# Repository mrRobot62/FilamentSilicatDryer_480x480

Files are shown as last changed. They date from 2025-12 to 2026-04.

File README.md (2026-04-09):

# ESP32-S3 Filament & SilicaGel Dryer UI

> English documentation is available in [README_EN.md](README_EN.md).
> Diese README ist die deutsche Hauptfassung.

## Management Summary

> [!NOTE]
>
> Große Teile der Dokumentation basieren auf aktuellen Source-Code Ständen, Analysen und Reverse-Engineering. Die Dokumentation wurde primär von ChatGPT
> zusammengefasst und ausgearbeitet.
> 

**Technische Grundlage (Kurzüberblick):**
- **UI/Host:** ESP32‑S3, 480×480 Touchdisplay, **LVGL 9.4.x**
- **Client/Powerboard:** ESP32‑WROOM steuert Aktuatoren (Heater, Fans, Motor, Lamp) und liefert Telemetrie
- **Kommunikation:** UART/TTL (Serial2), ASCII‑Protokoll mit CRLF (Host ↔ Client)
- **Temperaturmessung:** externer **K‑Type Sensor** über **MAX31856** (zusätzliche Genauigkeit/Plausibilität)

Der **ESP32-S3 Filament & Silicat Dryer** ist ein spezialisiertes Steuer- und Bedienkonzept für einen kombinierten
Filament- und Silicagel-Trockner im Umfeld des FDM-3D-Drucks.

Beim FDM-3D-Druck stellt **Feuchtigkeit im Filament** eine der größten Qualitätsrisiken dar. Unterschiedliche Materialien
wie PLA, PETG, ABS, ASA oder technische Kunststoffe reagieren sehr unterschiedlich auf Feuchtigkeit und benötigen
jeweils **eigene Trocknungstemperaturen und Trocknungszeiten**.

Zusätzlich wird Filament häufig zusammen mit **Silicagel** gelagert, das Feuchtigkeit aufnimmt. Dieses Silicagel muss
regelmäßig regeneriert werden, was eine Trocknung bei hohen Temperaturen (typischerweise über 100 °C) über definierte
Zeitspannen erfordert.

Der hier beschriebene Filament-Silicat-Dryer verfolgt deshalb einen **All-in-One-Ansatz**:
- gleichzeitige Trocknung von bis zu zwei Filamentrollen
- Regeneration von Silicagel in einem rotierenden Korb
- Nutzung robuster, vorhandener Hardware eines Mini-Backofens
- vollständiger Ersatz der ursprünglichen Anzeige- und Steuerlogik

Die bestehende Hersteller-Hardware wurde **analysiert und reverse-engineered**. Das Powerboard inklusive Ansteuerung
von Heizung, Lüftern, Motor und Sensorik wurde unverändert weiterverwendet. Die ursprüngliche Benutzeroberfläche
(7-Segment-Anzeige, LEDs, einfache Tasterlogik) wurde vollständig entfernt und durch dieses Projekt ersetzt.

Das Ergebnis ist ein **sicheres, transparentes und erweiterbares System**, das sowohl für den täglichen Betrieb als auch
für Wartung, Service und Weiterentwicklung geeignet ist.

## Aktueller Release-Stand

- Version: `0.7.2`
- Fokus:
  - konfigurierbarer Parameterscreen auf dem HOST
  - NVM-persistente Fast-Shortcut- und Heater-Curve-Parameter
  - Display-Timeout mit einstellbarem Dimmfaktor und Wake-on-Touch-Schutz

## Sprache / Language

- Deutsche Hauptfassung: [README.md](README.md)
- Englische Fassung: [README_EN.md](README_EN.md)

> [!WARNING]
> 
> **USB darf nicht angeschlossen werden, während das Gerät am 230-V-Netz betrieben wird.** <br>
> Durch netzseitige Bezüge des PowerBoards können beim Anstecken von USB gefährliche Potentialunterschiede entstehen, die ESP32 oder PC beschädigen.<br>
> USB nur bei gezogenem Netzstecker, mit USB-Isolator oder über Trenntrafo verwenden.

# Grundgerät - EMPHSISM AFTO-1505D
Heißluftfritteuse 14L Airfryer Mini Backofen, Emphsism Heissluftfritteuse XXL Minibackofen 1800W

Link: https://www.amazon.de/Heißluftfritteuse-Emphsism-Heissluftfritteuse-Minibackofen-Zubehörteile/dp/B0D5QQ4SW4

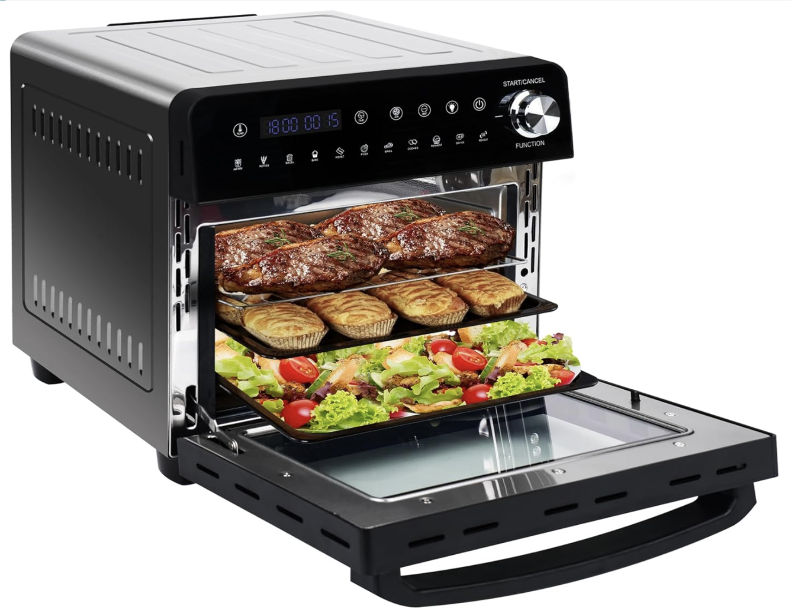
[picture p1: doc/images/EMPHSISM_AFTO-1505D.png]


## B-Ware kaufen !
> Die Geräte gibt es aber als B-Ware (ich habe mir ein solches Gerät gekauft). Kosten ca. 60€.
> Fehler in meinem Gerät (der Drehencoder funktionierte nicht - allerdings nur ein mechanischer Fehler :-) )

## Screenshots (Platzhalter)

### Main-Screen
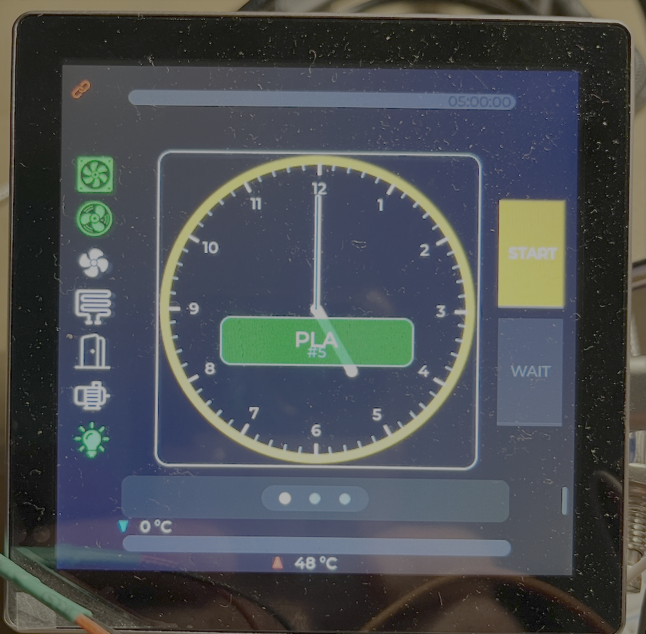
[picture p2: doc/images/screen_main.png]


### Filament-Config
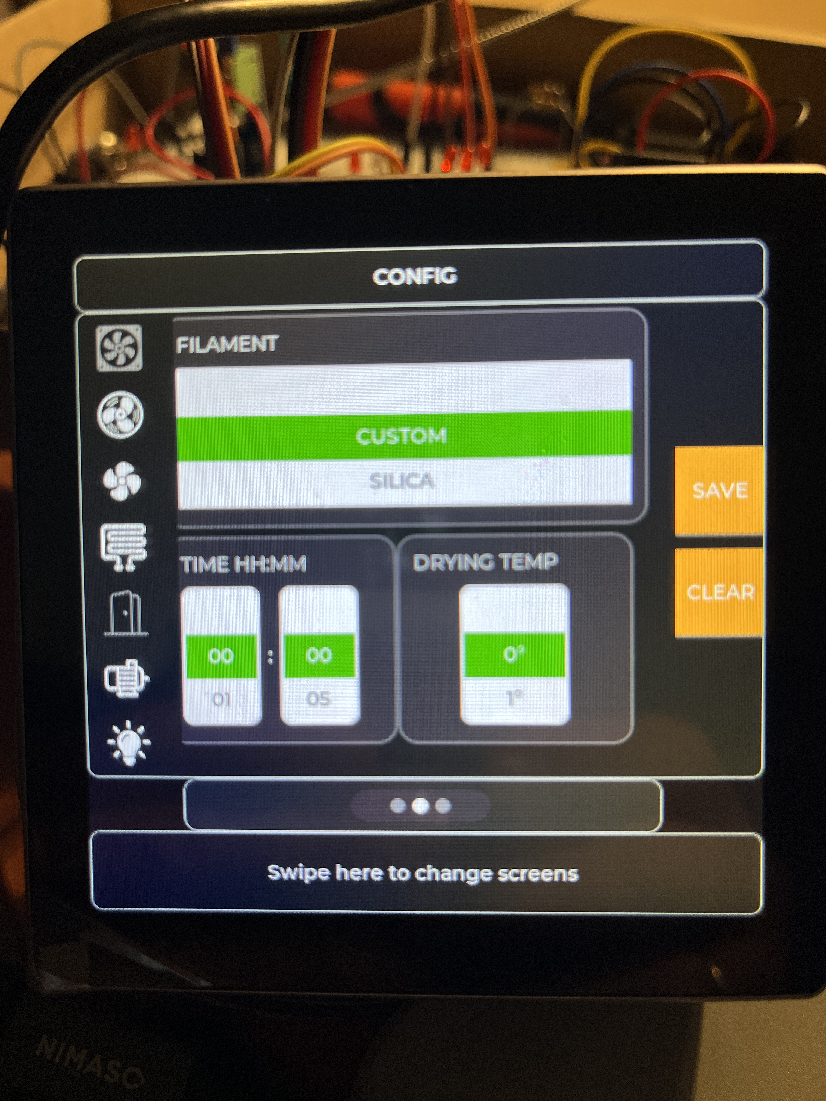
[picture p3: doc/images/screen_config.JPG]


### Hardware-Debug 
Diesen Screen nur mit **"Vorsicht"**  nutzen !

### Parameterscreen
- Der bisher ungenutzte LOG-Screen wurde durch `Parameter` ersetzt.
- Der Screen ist vertikal scrollbar und verwaltet hostseitige Grundparameter.
- Aktuell konfigurierbar:
  - Filament-Shortcuts fuer die vier Fast-Buttons aus `screen_main`
  - Heater-Curve-Parameter fuer die Presets `45C`, `60C`, `80C`, `100C`
  - `Display timeout` mit `Dimmfaktor (%)` und `Dimm-Timeout (min)`
- `SAVE` und `RESET` schreiben die Werte in das HOST-NVM und fuehren danach einen Reboot aus.
- Der erste Touch nach einem gedimmten Display hellt nur auf und loest absichtlich keine Funktion aus.

## Dokumentation

- Dokumentationsindex: [doc/README.md](doc/README.md)
- Softwarearchitektur: [doc/02_software_architecture/README.md](doc/02_software_architecture/README.md)
- User Guide: [doc/03_user_guide/README.md](doc/03_user_guide/README.md)

## Installation

> [!WARNING]
> 
> **!!!!! NIE USB verwenden, wenn Netzstecker eingesteckt ist !!!!!!!**

> [Installationsanweisung](doc/filament-silicagel-dryer_installation_v2.md)

## Systemarchitektur – Überblick

Zentrales Prinzip: **Oven Runtime State als Single Source of Truth**

### Komponenten-Diagramm
```mermaid
flowchart LR

  subgraph UX["UX Controller (ESP32 S3)"]
    S3["ESP32 S3 MCU"]
    TFT["480x480 Touch Display"]
    TOUCH["Touch Controller"]
    IO["GPIO Outputs"]
  end

  subgraph CLIENT["IO Controller (ESP32 WROOM)"]
    WROOM["ESP32 WROOM MCU"]
    UART2["UART TTL Interface"]
    OUT["Output Mask"]
    IN["Status Inputs"]
  end

  subgraph PWR["Powerboard (Reverse Engineered)"]
    PB["Powerboard Logic"]
    REL["Relays and Power Drivers"]
    SNS["Door and Safety Signals"]
  end

  subgraph SENS["External Temperature Sensor"]
    TC["K Type Thermocouple"]
    AMP["MAX31856 Interface"]
  end

  %% Connections
  S3 -->|"SPI or RGB"| TFT
  S3 -->|"I2C or SPI"| TOUCH

  S3 <-->|"UART TTL"| UART2
  UART2 <-->|"Serial Link"| WROOM

  WROOM -->|"Control Lines"| OUT
  OUT --> PB
  PB --> REL

  PB -->|"Status Bits"| IN
  IN --> WROOM

  TC -->|"Thermocouple"| AMP
  AMP -->|"SPI"| S3

  %% Notes
  NOTE1["UI never drives power directly"]
  NOTE2["Powerboard is authoritative source"]

  NOTE1 -.-> S3
  NOTE2 -.-> PB
```

## Entwicklungsphasen

> **Hinweis:**<br>
> **T1** (Display-/Touch‑Bring‑up) und <br>
> **T2** (erster LVGL‑Architektur‑Ansatz) waren bewusst frühe Grundlagenphasen. <br>
> Die wesentlichen, produktionsnahen Implementierungen starten ab <br>
> **T3** und sind entsprechend ab dort detailliert dokumentiert.

Siehe Dokumente unter `/docs`:
- [Entwicklungsphase T3 - Architektur / UX](doc/ESP32-S3_UI_T3_Zusammenfassung.md)
- [Entwicklungsphase T4 - screen_main](doc/ESP32-S3_UI_T4_Zusammenfassung.md)
- [Entwicklungsphase T5 - oven-logic](doc/ESP32-S3_UI_T5_Zusammenfassung.md)
- [Entwicklungsphase T6 - host/client Kommunikation (architektur/test)](doc/ESP32-S3_UI_T6_Zusammenfassung.md)
- [Entwicklungsphase T7 - host/client UX Integration](doc/ESP32-S3_UI_T7_Zusammenfassung.md)
- [Entwicklungsphase T8 - screen_dbg_hw](doc/ESP32-S3_UI_T8_Zusammenfassung.md)

## ⚠️ Sicherheitshinweis: USB-Verbindung im laufenden Betrieb

### Hintergrund
Das PowerBoard schaltet netzbetriebene Verbraucher (230 V AC) über TRIAC-basierte
Leistungsstufen. Obwohl der Niedervoltbereich (5 V / 3,3 V) funktional getrennt ist,
bestehen **elektrische Bezüge zum Netzbereich**, z. B. über TRIAC-Gate-Schaltungen,
Schutzdioden (PD-Netzwerke) und EMV-Strukturen.

Der ESP32 wird direkt vom PowerBoard versorgt und ist daher Teil dieser elektrischen
Domäne.

### Risiko beim Anschluss von USB
Beim Anschluss eines USB-Kabels wird die **USB-Masse des PCs/Laptops** direkt mit der
**Masse des ESP32** verbunden. Ist das Gerät gleichzeitig mit dem 230-V-Netz verbunden,
kann dies zu folgenden Problemen führen:

- ungewollten **Potentialunterschieden** zwischen PC und Gerät,
- **Beschädigung des ESP32**, des PowerBoards oder des USB-Ports am PC,
- im ungünstigen Fall zu gefährlichen Fehlerströmen durch EMV-Kopplungen oder Transienten.

Auch wenn keine direkte Gleichspannungsverbindung zu Phase (L) oder Neutralleiter (N)
messbar ist, können **kapazitive Kopplungen und kurzzeitige Überspannungen** auftreten.

### Verbindliche Regel
**USB darf nicht angeschlossen werden, während das Gerät am 230-V-Netz betrieben wird.**

### Erlaubte Nutzung
Eine USB-Verbindung ist nur unter einer der folgenden Bedingungen zulässig:
- Das Gerät ist vollständig **vom Netz getrennt** (Netzstecker gezogen), oder
- es wird ein **USB-Isolator** verwendet, oder
- das Gerät wird über eine **galvanisch getrennte Versorgung** betrieben
  (z. B. Trenntrafo).

### Empfehlung
- Firmware-Updates und Debugging **nur im spannungslosen Zustand** durchführen.
- Für Debugging im Betrieb ausschließlich **galvanisch isolierte Werkzeuge** verwenden.
- Der ESP32 ist als **interne Gerätelektronik** zu betrachten und nicht als
  USB-sichere Entwicklungsplattform.

Die Nichtbeachtung dieser Hinweise kann zu Hardware-Schäden führen.

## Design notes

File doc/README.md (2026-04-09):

# Documentation

This folder was restructured on top of the `v0.7.1` code line.

The active documentation is intentionally reduced to three maintained sections:

1. [Reverse Engineering and Hardware](01_reverse_engineering_and_hardware/README.md)
2. [Software Architecture](02_software_architecture/README.md)
3. [User Guide](03_user_guide/README.md)

Legacy material is still available in the archive:

- [Archive snapshot before the reorganization](archive/pre_reorg_v0.7.1/README.md)

## Scope of the active documentation

The new structure reflects the current product split:

- `HOST`: ESP32-S3 UI controller with LVGL, runtime state, parameter storage and communication control
- `CLIENT`: ESP32-WROOM hardware controller for outputs, telemetry and safety gating
- Reverse-engineered oven power board reused as actuator and supply stage

## Recommended next additions

The requested structure is complete for the current start. The next useful additions would be:

- a dedicated manufacturing and wiring guide
- a test and validation section
- a release and update workflow section

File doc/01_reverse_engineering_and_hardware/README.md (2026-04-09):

# Reverse Engineering and Hardware

This section documents the physical platform that the software is built around.

Contents:

1. [Power board analysis](01_powerboard_analysis.md)
2. [LVGL display and panel specifics](02_lvgl_display.md)
3. [KiCad hardware files](03_kicad.md)

## Current hardware split

- Base appliance: EMPHSISM AFTO-1505D mini oven / air fryer platform
- Reused original power board: heater, fans, lamp, motor, mains-side supply
- New `HOST` board: ESP32-S3 with 480x480 LVGL touch display
- New `CLIENT` board: ESP32-WROOM interface to the reused power board

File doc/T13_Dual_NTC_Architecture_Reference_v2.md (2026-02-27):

# T13 -- Dual‑NTC Architecture Reference (Erweitert)

Version: T13.0\
Status: Stabil, Referenzbasis für T14 SafetyGuard\
Zielgruppe: Entwickler, Techniker, Elektronik‑Interessierte

------------------------------------------------------------------------

# Übersicht

Die T13‑Architektur implementiert ein temperaturgeregeltes
Filament‑Trocknungssystem mit zwei physikalischen Temperatursensoren
(NTCs).\
Die Regelung erfolgt vollständig auf dem Host‑Controller (ESP32‑S3).

Die Architektur trennt bewusst:

-   Temperaturregelung (Control)
-   Sicherheit (Safety)
-   Hardwarezugriff (Client)
-   Darstellung (UI)

------------------------------------------------------------------------

# Sensor‑Architektur

## Chamber‑NTC (Control Sensor)

Eigenschaften:

-   10k NTC
-   10k Referenzwiderstand
-   angeschlossen an ADS1115 Channel 1
-   misst reale Lufttemperatur im Trocknungsraum

Verwendung:

-   einzige Grundlage der Temperaturregelung
-   einzige Grundlage für UI‑Anzeige
-   einzige Grundlage für Heater‑Steuerung

------------------------------------------------------------------------

## Hotspot‑NTC (Safety Sensor)

Eigenschaften:

-   100k NTC
-   100k Referenzwiderstand
-   angeschlossen an ADS1115 Channel 0
-   misst Nähe zur Heizquelle

Verwendung:

-   ausschließlich Sicherheitsüberwachung
-   keine Verwendung für Regelung

------------------------------------------------------------------------

# Systemarchitektur

``` mermaid
flowchart LR
    ChamberNTC --> ADS1115
    HotspotNTC --> ADS1115

    ADS1115 --> ClientESP32
    ClientESP32 -->|STATUS Frame| HostESP32

    HostESP32 --> OvenControl
    OvenControl --> HeaterControl

    OvenControl --> UI
```

------------------------------------------------------------------------

# Datenfluss im Betrieb

``` mermaid
sequenceDiagram
    participant ChamberNTC
    participant ADS1115
    participant Client
    participant Host
    participant OvenControl

    ChamberNTC->>ADS1115: Analogspannung
    ADS1115->>Client: ADC Raw Value
    Client->>Host: STATUS Frame
    Host->>OvenControl: Update runtimeState.tempChamberC
    OvenControl->>HeaterControl: ON / OFF
```

------------------------------------------------------------------------

# STATUS‑Protokoll (T13)

Frame Format:

    C;STATUS;<mask>;<adc0>;<adc1>;<adc2>;<adc3>;<tempHotspot_dC>;<tempChamber_dC>

Beispiel:

    C;STATUS;0020;26833;14065;0;0;-32768;227

Bedeutung:

-   adc1 = Chamber Sensor
-   tempChamber_dC = Chamber Temperatur in 0.1°C

------------------------------------------------------------------------

# Regelarchitektur (Control Layer)

Regelung basiert ausschließlich auf:

    tempChamberC

Nicht verwendet:

    tempHotspotC

------------------------------------------------------------------------

# Regel‑State‑Machine

``` mermaid
stateDiagram-v2
    [*] --> Idle
    Idle --> Heating : temp < target‑hysterese
    Heating --> Stabilizing : temp nahe target
    Stabilizing --> Heating : temp fällt
    Stabilizing --> Idle : target erreicht
```

------------------------------------------------------------------------

# Technische Implementierung

## Übersicht der Software‑Komponenten

``` mermaid
flowchart TD

    subgraph Client (ESP32‑WROOM)
        ADS[ADS1115 Driver]
        NTCConv[NTC Conversion]
        StatusGen[ProtocolStatus Generator]
    end

    subgraph Host (ESP32‑S3)
        HostComm[HostComm RX]
        ProtocolParse[Protocol Parser]
        RuntimeState[OvenRuntimeState]
        ControlLoop[Control Loop]
        Heater[Heater Output]
    end

    ADS --> NTCConv
    NTCConv --> StatusGen
    StatusGen --> HostComm

    HostComm --> ProtocolParse
    ProtocolParse --> RuntimeState
    RuntimeState --> ControlLoop
    ControlLoop --> Heater
```

------------------------------------------------------------------------

## Client‑Implementierung

Dateien:

-   FSD_Client.cpp
-   ClientComm.cpp

Aufgaben:

-   ADS1115 auslesen
-   ADC Werte in Temperatur konvertieren
-   STATUS Frame erzeugen
-   STATUS über UART senden

Beispielablauf:

``` cpp
adcRaw[1] = ads.readADC_SingleEnded(1);
tempChamber_dC = ntc_convert(adcRaw[1]);
sendStatusFrame();
```

------------------------------------------------------------------------

## Host‑Implementierung

Dateien:

-   oven.cpp
-   HostComm.cpp

Ablauf:

1.  STATUS Frame empfangen
2.  Werte in runtimeState übernehmen
3.  Regelalgorithmus ausführen
4.  Heater setzen

``` mermaid
flowchart TD
    STATUS[STATUS Frame] --> Parse
    Parse --> runtimeState
    runtimeState --> ControlLogic
    ControlLogic --> HeaterOutput
```

------------------------------------------------------------------------

## OvenRuntimeState

Zentrale Datenstruktur:

Beispiel:

    struct OvenRuntimeState
    {
        float tempChamberC;
        float tempHotspotC;
        float tempTargetC;

        bool heaterOn;
    };

Single Source of Truth für:

-   Regelung
-   UI
-   Logging

------------------------------------------------------------------------

## Regelalgorithmus (T13 Control Core)

Prinzip:

-   Thermostat‑basierte Regelung
-   Hysterese
-   overshoot prevention

Beispiel:

    if tempChamberC < target‑hysterese → heater ON
    if tempChamberC > target → heater OFF

------------------------------------------------------------------------

# Sicherheitsarchitektur

Safety erfolgt über:

-   Host‑Safety Logic
-   (zukünftig erweitert in T14 SafetyGuard Client)

------------------------------------------------------------------------

# Ergebnis der T13 Architektur

Eigenschaften:

-   stabile Regelung
-   keine Overshoot‑Instabilität
-   klare Trennung von Control und Safety
-   deterministic behaviour

------------------------------------------------------------------------

# Bedeutung für T14

T13 dient als stabile Grundlage für:

-   SafetyGuard Client Layer
-   Hardware Fail‑Safe Mechanismen

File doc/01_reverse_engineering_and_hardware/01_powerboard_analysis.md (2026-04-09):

# Power Board Analysis

## Goal

The original oven power board is reused instead of being redesigned from scratch. The reverse-engineering work exists to understand:

- power conversion and low-voltage supply
- actuator paths for heater, fans, lamp and motor
- door and sensor signals
- risks when connecting custom ESP32 hardware

## What is currently known

The reverse-engineering documents archived from the previous structure show a consistent pattern:

- the board contains the mains-side power stage and the low-voltage supply
- the heater is switched through a relay path
- 230 V loads such as lamp, motor and fan stages are driven through optocoupler / triac style paths
- the board exposes low-voltage control and status connections that are now driven by the `CLIENT`

## Functional block view

```mermaid
flowchart TD
    AC["230 V AC input"] --> PSU["Offline PSU section"]
    PSU --> LV["Low-voltage rail"]
    LV --> CLIENT["ESP32-WROOM client board"]

    CLIENT --> RELAY["Heater relay driver"]
    CLIENT --> TRIAC["Triac / optocoupler outputs"]
    CLIENT --> INPUTS["Door and sensor inputs"]

    RELAY --> HEATER["Heater"]
    TRIAC --> FAN12["12 V fan"]
    TRIAC --> FAN230["230 V fan"]
    TRIAC --> MOTOR["Silica basket motor"]
    TRIAC --> LAMP["Lamp"]

    INPUTS --> CLIENT
```

## Control lines used by the current firmware

The active output bit mapping is defined in `include/output_bitmask.h`:

- `BIT_FAN12V`
- `BIT_FAN230V`
- `BIT_LAMP`
- `BIT_SILICA_MOTOR`
- `BIT_FAN230V_SLOW`
- `BIT_DOOR`
- `BIT_HEATER`

The current `CLIENT` firmware treats the power board as hardware-authoritative:

- commands arrive from `HOST`
- output application happens on `CLIENT`
- telemetry and effective output truth are reported back to `HOST`
- safety gating remains on the `CLIENT`

## Important safety note

The board is mains-related. Existing project warnings remain valid:

- do not attach USB while the oven is connected to mains
- use isolation or disconnected mains supply during development
- treat the board as non-trivial mains hardware, not as a benign low-voltage module

## Source of historic details

Detailed pin traces, annotated photos and earlier analysis notes remain in:

- `doc/archive/pre_reorg_v0.7.1/legacy_docs/reverse_engineering/`
- `doc/archive/pre_reorg_v0.7.1/legacy_docs/images/`

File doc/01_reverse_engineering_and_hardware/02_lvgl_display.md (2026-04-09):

# LVGL Display and Panel Specifics

## Hardware identity

The current `HOST` uses an ESP32-S3 with a 480x480 touch display stack.

The code base references:

- panel: `HSD040BPN1-A00`
- controller family: `ST7701`
- backlight GPIO: `38`
- LVGL version: `9.4.0`

Relevant implementation files:

- `src/app/display/panel_hsd040bpn1.h`
- `src/app/display/display_hsd040bpn1.h`
- `src/app/display/display_hsd040bpn1.cpp`

## Integration characteristics

The display integration is not generic boilerplate. It has panel-specific constraints:

- RGB panel interface on the ESP32-S3
- separate register initialization sequence for the ST7701 family
- explicit backlight control
- touch integration handled separately from the display bring-up

## Known quirks from the current implementation history

- stable operation was achieved with a lower pixel clock than initially tested
- color order and pixel format needed panel-specific tuning
- the initialization sequence is tightly coupled to this exact panel family

## Display stack overview

```mermaid
flowchart LR
    APP["UI screens"] --> LVGL["LVGL 9.4"]
    LVGL --> GFX["Arduino_GFX display wrapper"]
    GFX --> RGB["ESP32-S3 RGB panel driver"]
    RGB --> ST7701["ST7701 init sequence"]
    ST7701 --> PANEL["HSD040BPN1 480x480 panel"]
    APP --> TOUCH["Touch controller"]
```

## Why this matters for documentation

This display section should remain separate because three concerns often get mixed up:

- panel electrical timing
- controller register initialization
- LVGL/UI behavior on top of a working framebuffer path

That separation will make future display bring-up changes less risky.

## Historic vendor files

Vendor packs, data sheets and flashing utilities are preserved in the archive:

- `doc/archive/pre_reorg_v0.7.1/legacy_docs/hardware/ESP32-S3 4848S04_Display/`

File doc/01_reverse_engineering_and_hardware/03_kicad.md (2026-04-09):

# KiCad

## Purpose

This section tracks the custom hardware files that belong to the adapted dryer controller setup.

## Available design assets

The repository already contains KiCad project files for the custom interface boards and variants.

Archived path:

- `doc/archive/pre_reorg_v0.7.1/legacy_docs/hardware/kicad/Filament-Silicagel-Dryer/`

Available project artifacts include:

- `.kicad_sch`
- `.kicad_pcb`
- `.kicad_pro`
- generated PDFs and gerbers
- alternative lochraster variants

## Recommended documentation baseline

The KiCad documentation should eventually describe:

1. which board is the currently valid build target
2. how the `HOST`, `CLIENT` and power board are wired together
3. which variants are legacy and which remain supported
4. where the series resistors, UART lines and sensor connections are placed

## Immediate interpretation of the current repository

Right now the KiCad data is valuable but not yet normalized. The archive keeps all variants, while the active documentation focuses on architecture first.

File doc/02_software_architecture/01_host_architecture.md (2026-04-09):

# HOST Architecture

## Responsibility

The `HOST` runs on the ESP32-S3 and owns:

- LVGL UI
- runtime state presented to the user
- drying logic and heater policy
- parameter persistence
- UART coordination with the `CLIENT`
- optional Wi-Fi / UDP diagnostics

The `HOST` does not directly drive the power board outputs.

## Main runtime modules

- `src/app/main.cpp`
- `src/app/oven/oven.cpp`
- `src/share/HostComm.cpp`
- `src/app/ui/**`
- `src/app/display/**`
- `src/app/host_parameters.cpp`

## Control flow

```mermaid
flowchart TD
    BOOT["setup()"] --> INIT["init UART, parameters, oven, UI"]
    INIT --> MAIN["main loop"]
    MAIN --> LVGL["LVGL tick and screen handling"]
    MAIN --> OVEN["oven runtime tick"]
    MAIN --> COMM["HostComm loop"]
    COMM --> STATUS["remote STATUS / ACK / PONG"]
    STATUS --> OVEN
    OVEN --> STATE["OvenRuntimeState"]
    STATE --> UI["screen rendering"]
    OVEN --> CMD["Host commands to client"]
```

## State model

The central host-side abstraction is `OvenRuntimeState` from `include/oven.h`.

It consolidates:

- target and measured temperatures
- effective actuator states from client telemetry
- communication health
- mode state such as `STOPPED`, `RUNNING`, `WAITING`, `POST`
- selected preset, heater profile and timing information

That state acts as the UI-facing single source of truth.

## Heater control model

The host decides heater intent, but not the final hardware truth.

The current logic in `oven.cpp` includes:

- preset-based target temperatures
- separate heater policies for low, mid, high and silica use cases
- min-on and min-off timing for relay protection
- hotspot and chamber safety limits
- comm-loss safe stop behavior

## Host architecture diagram

```mermaid
flowchart LR
    subgraph Host["ESP32-S3 HOST"]
        UI["LVGL screens"]
        OVEN["oven.cpp"]
        PARAM["host parameters"]
        COMM["HostComm"]
        DISP["display + touch"]
        NET["UDP diagnostics"]
    end

    UI --> OVEN
    PARAM --> OVEN
    OVEN --> UI
    OVEN --> COMM
    COMM --> OVEN
    DISP --> UI
    NET -. optional .-> OVEN
```

## Design consequence

The host is the policy and UX layer. It should remain free of assumptions that bypass client telemetry.

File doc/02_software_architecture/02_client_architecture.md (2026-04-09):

# CLIENT Architecture

## Responsibility

The `CLIENT` runs on the ESP32-WROOM and is the hardware-facing controller.

It owns:

- UART reception from the `HOST`
- output application to the power board
- telemetry generation
- safety gating close to the hardware
- sensor readout used for status reporting

## Main runtime modules

- `src/client/FSD_Client.cpp`
- `src/client/ClientComm.cpp`
- `src/client/heater_io.cpp`
- `src/client/sensor_ntc.cpp`
- `src/share/protocol.cpp`

## Architectural rules visible in the code

- incoming UART callbacks do not directly switch outputs
- mask changes are marked pending and applied from the main loop
- effective output truth is reported back, not just the requested mask
- host timeout forces a safe output mask
- door and thermal conditions can gate outputs locally

## Client processing diagram

```mermaid
flowchart TD
    RX["UART RX"] --> COMM["ClientComm"]
    COMM --> PARSE["parse host command"]
    PARSE --> PENDING["store pending mask / request"]
    PENDING --> LOOP["client loop"]
    LOOP --> APPLY["apply outputs safely"]
    LOOP --> SENS["read door / NTC / ADC"]
    APPLY --> STATUS["compose ProtocolStatus"]
    SENS --> STATUS
    STATUS --> TX["send STATUS / ACK / PONG"]
```

## Safety model

The client is deliberately hardware-authoritative:

- if the host disappears, the client forces a safe state
- if an output should not remain active due to safety conditions, the effective mask can differ from the requested mask
- the host UI must therefore trust client telemetry, not host intent alone

## Output mapping

The active output map is defined in `include/output_bitmask.h`:

- fan 12 V
- fan 230 V
- lamp
- silica motor
- fan 230 V slow
- door status bit
- heater

## Design consequence

The client should stay narrow and deterministic. Business logic belongs on the host; electrical truth belongs on the client.

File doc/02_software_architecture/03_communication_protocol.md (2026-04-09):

# Communication Protocol

## Role

The `HOST` and `CLIENT` communicate over `Serial2` with a line-based ASCII protocol.

Shared definitions live in:

- `include/protocol.h`
- `src/share/protocol.cpp`
- `src/share/HostComm.cpp`
- `src/client/ClientComm.cpp`

## Transport characteristics

- UART / TTL link
- messages are line-based
- frames are terminated with `CRLF`
- protocol is human-readable ASCII

## Message families

### Host to client

- `H;SET;XXXX`
- `H;UPD;SSSS;CCCC`
- `H;TOG;TTTT`
- `H;GET;STATUS`
- `H;PING`
- `H;RST`

### Client to host

- `C;ACK;SET;MMMM`
- `C;ACK;UPD;MMMM`
- `C;ACK;TOG;MMMM`
- `C;STATUS;...`
- `C;PONG`
- `C;RST`

## Status payload

`ProtocolStatus` currently contains:

- `outputsMask`
- `adcRaw[4]`
- `tempHotspot_dC`
- `tempChamber_dC`

The chamber temperature is the main control/UI temperature. The hotspot temperature is the safety temperature.

The current `C;STATUS` wire format is:

- `C;STATUS;<mask>;<a0>;<a1>;<a2>;<a3>;<hotspot_dC>;<chamber_dC>`

Some legacy comments in the code still describe the older single-temperature variant, but the codec implementation already uses the two-temperature format above.

## Protocol sequence

```mermaid
sequenceDiagram
    autonumber
    participant Host as HOST
    participant Client as CLIENT

    Host->>Client: PING
    Client-->>Host: PONG

    Host->>Client: SET or UPD or TOG
    Client-->>Host: ACK

    loop Periodic status polling
        Host->>Client: GET STATUS
        Client-->>Host: STATUS with mask ADC hotspot chamber
    end
```

## Robustness principles

The current implementation shows several explicit protocol design choices:

- both sides assemble complete lines before parsing
- stray bytes and partial garbage are tolerated up to a limit
- host and client both use timeout-based link supervision
- the host can safe-stop on comm loss
- the client can force safe outputs on host timeout

## Why the protocol matters architecturally

The protocol is not only transport. It is the contract that enforces the split between host policy and client hardware truth.

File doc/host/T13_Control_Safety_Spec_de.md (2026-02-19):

# T13 Steuerungs- und Sicherheits-Spezifikation

**Projekt:** FilamentSilicatDryer_480x480\
**Architektur-Version:** T13 (Dual-NTC, relaisfreundliche
Pulssteuerung)\
**Datum:** 2026-02-19

------------------------------------------------------------------------

# Änderungsprotokoll

## T13 (2026-02-19)

-   Einführung der Dual-NTC Architektur:
    -   `tempHotspot` (Sicherheitsüberwachung und thermische Dynamik)
    -   `tempChamber` (Primäre Regel- und UI-Temperatur)
-   Vollständige Entfernung des PT1/Bias-Thermalmodells.
-   Einführung preset-basierter Kammergrenzen (`chamberMaxC`).
-   Einführung eines relaisfreundlichen adaptiven Pulsreglers.
-   Einführung eines mehrstufigen Sicherheitssystems:
    -   Preset-basierte Kammergrenze
    -   Absolute Kammergrenze
    -   Hotspot Soft- und Hard-Grenzen
    -   Fail-Safe Sensorbehandlung

------------------------------------------------------------------------

# Systemübersicht

Das System besteht aus:

-   Host: ESP32-S3 (UI, Regelungslogik, Sicherheitslogik)
-   Client: ESP32-WROOM (Sensorerfassung, Aktorsteuerung)
-   Temperatursensoren: Zwei unabhängige NTC-Sensoren über ADS1115 ADC

Temperaturrollen:

  Sensor        Zweck
  ------------- ------------------------------------------------------
  tempChamber   Primäre Regeltemperatur
  tempHotspot   Sicherheitsüberwachung und dynamische Heizbegrenzung

Der Host ist die **Single Source of Truth** für alle Regel- und
Sicherheitsentscheidungen.

------------------------------------------------------------------------

# Sensorerfassung (Client)

ADC: ADS1115\
Gain: ±6.144 V\
Auflösung: 16-bit signed integer

Mapping:

  ADS Kanal   Zweck
  ----------- -------------
  CH0         tempHotspot
  CH1         tempChamber
  CH2         Reserviert
  CH3         Reserviert

RAW-Werte werden unverändert übertragen.

Temperaturübertragungseinheit:

-   deci-Grad Celsius (°C × 10)
-   Beispiel: 509 = 50.9°C

------------------------------------------------------------------------

# STATUS Protokollframe

Format:

    C;STATUS;<mask_hex>;<adc0>;<adc1>;<adc2>;<adc3>;<tempHotspot_dC>;<tempChamber_dC>

Beispiel:

    C;STATUS;0035;12345;11890;0;0;509;372

------------------------------------------------------------------------

# Preset-Modell

Jedes Preset definiert:

  Feld          Beschreibung
  ------------- -------------------------------------
  targetC       Zieltemperatur
  toleranceC    Hysterese
  chamberMaxC   Maximale zulässige Kammertemperatur

Beispiel (Silicagel Preset):

  Feld          Wert
  ------------- -------
  targetC       105.0
  toleranceC    2.0
  chamberMaxC   110.0

Regelband:

    lo = targetC − toleranceC
    hi = targetC + toleranceC

Beispiel:

    103°C … 107°C

------------------------------------------------------------------------

# Sicherheitsmodell

Sicherheitsebenen (höchste Priorität zuerst):

## Ebene 1 --- Absolute Kammergrenze

    CHAMBER_HARD_MAX_C = 120°C

Bei Überschreitung:

    Heater sofort AUS

## Ebene 2 --- Preset-Kammergrenze

    capC = min(chamberMaxC, CHAMBER_HARD_MAX_C)

Bei Überschreitung:

    Heater AUS

## Ebene 3 --- Hotspot Sicherheit

Relative Grenzwerte:

    HOTSPOT_SOFT_MAX_C = capC + 15°C
    HOTSPOT_HARD_MAX_C = capC + 30°C

Verhalten:

  Bedingung       Aktion
  --------------- ---------------------------
  ≥ Soft-Grenze   Verlängerung der OFF-Zeit
  ≥ Hard-Grenze   Heater AUS

Globale Begrenzung:

    HOTSPOT_HARD_MAX_C ≤ 200°C

------------------------------------------------------------------------

# Pulsregler (relaisfreundlich)

Relais benötigen langsame Schaltzyklen.

Standardparameter:

    HEAT_MS_MIN = 2000
    HEAT_MS_MAX = 8000

    REST_MS_MIN = 6000
    REST_MS_MAX = 60000

    MIN_TOGGLE_MS = 2000

Verhalten nahe Zieltemperatur:

    nearBandC = 3.0°C
    restNearTargetMinMs = 20000

Verhalten:

  Bedingung                    Ergebnis
  ---------------------------- ------------------------------------
  Weit unter Ziel              Moderate Heizpulse
  Nahe Ziel                    Minimale Heizzeit, lange OFF-Phase
  Schneller Hotspot-Anstieg    Verlängerte OFF-Phase
  Sicherheitsgrenze erreicht   Heater AUS

------------------------------------------------------------------------

# Fail-Safe Verhalten

Ungültiger Temperaturwert:

    temp = -32768

Verhalten:

    Heater AUS
    Optional Fault-Status

------------------------------------------------------------------------

# Regelautorität

Regelentscheidungen basieren ausschließlich auf:

    tempChamberC

Hotspot wird nur verwendet für:

-   Sicherheit
-   Timing-Anpassung

UI zeigt:

    tempChamberC

------------------------------------------------------------------------

# Beispiel: Silicagel Betrieb

Preset:

    target = 105°C
    tolerance = 2°C
    max = 110°C

Stabiler Betriebsbereich:

    100°C … 110°C

Overshoot wird verhindert durch:

-   chamberMaxC
-   Pulsregler
-   Hotspot-Sicherheitslogik

------------------------------------------------------------------------

# Implementierungsanforderungen

Host muss:

-   STATUS Frame parsen
-   Temperaturen verwalten
-   Pulsregler ausführen
-   Sicherheitslogik anwenden
-   Heater über Bitmaske steuern

Client muss:

-   ADS1115 lesen
-   NTC Temperaturen berechnen
-   STATUS Frames senden

------------------------------------------------------------------------

# Ende der Spezifikation

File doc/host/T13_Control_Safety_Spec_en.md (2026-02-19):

# T13 Control & Safety Specification

**Project:** FilamentSilicatDryer_480x480\
**Architecture Version:** T13 (Dual‑NTC, Relay‑friendly Pulse Control)\
**Date:** 2026‑02‑19

------------------------------------------------------------------------

# Change‑Log

## T13 (2026‑02‑19)

-   Introduced Dual‑NTC architecture:
    -   `tempHotspot` (Safety & thermal dynamics monitoring)
    -   `tempChamber` (Primary control & UI temperature)
-   Removed PT1/Bias thermal model completely.
-   Introduced preset‑based chamber limits (`chamberMaxC`).
-   Introduced relay‑friendly adaptive pulse scheduler.
-   Introduced multi‑layer safety model:
    -   Chamber preset cap
    -   Chamber hard cap
    -   Hotspot soft and hard caps
    -   Sensor fail‑safe handling

------------------------------------------------------------------------

# System Overview

The system consists of:

-   Host: ESP32‑S3 (UI, control logic, safety logic)
-   Client: ESP32‑WROOM (sensor acquisition, actuator control)
-   Temperature sensors: Two independent NTC sensors connected via
    ADS1115 ADC

Temperature roles:

  Sensor        Purpose
  ------------- -----------------------------------------------
  tempChamber   Primary control temperature
  tempHotspot   Safety monitoring and dynamic heating limiter

The Host is the **single source of truth** for all control and safety
decisions.

------------------------------------------------------------------------

# Sensor Acquisition (Client)

ADC: ADS1115\
Gain: ±6.144 V\
Resolution: 16‑bit signed integer

Mapping:

  ADS Channel   Purpose
  ------------- -------------
  CH0           tempHotspot
  CH1           tempChamber
  CH2           Reserved
  CH3           Reserved

RAW values transmitted unmodified.

Temperature transmission unit:

-   deci‑degrees Celsius (°C × 10)
-   Example: 509 = 50.9°C

------------------------------------------------------------------------

# STATUS Protocol Frame

Format:

    C;STATUS;<mask_hex>;<adc0>;<adc1>;<adc2>;<adc3>;<tempHotspot_dC>;<tempChamber_dC>

Example:

    C;STATUS;0035;12345;11890;0;0;509;372

------------------------------------------------------------------------

# Preset Model

Each preset defines:

  Field         Description
  ------------- -------------------------------------
  targetC       Control target temperature
  toleranceC    Hysteresis tolerance
  chamberMaxC   Maximum allowed chamber temperature

Example (Silicagel preset):

  Field         Value
  ------------- -------
  targetC       105.0
  toleranceC    2.0
  chamberMaxC   110.0

Control band:

    lo = targetC − toleranceC
    hi = targetC + toleranceC

Example:

    103°C … 107°C

------------------------------------------------------------------------

# Safety Model

Safety layers (highest priority first):

## Layer 1 --- Chamber Hard Limit

    CHAMBER_HARD_MAX_C = 120°C

If exceeded:

    Heater OFF immediately

## Layer 2 --- Preset Chamber Limit

    capC = min(chamberMaxC, CHAMBER_HARD_MAX_C)

If exceeded:

    Heater OFF

## Layer 3 --- Hotspot Safety

Relative thresholds:

    HOTSPOT_SOFT_MAX_C = capC + 15°C
    HOTSPOT_HARD_MAX_C = capC + 30°C

Behavior:

  Condition    Action
  ------------ ------------------------
  ≥ soft max   Increase REST duration
  ≥ hard max   Heater OFF

Global clamp:

    HOTSPOT_HARD_MAX_C ≤ 200°C

------------------------------------------------------------------------

# Pulse Scheduler (Relay‑Friendly Control)

Relay switching constraints require slow switching.

Default timing parameters:

    HEAT_MS_MIN = 2000
    HEAT_MS_MAX = 8000

    REST_MS_MIN = 6000
    REST_MS_MAX = 60000

    MIN_TOGGLE_MS = 2000

Near‑target behavior:

    nearBandC = 3.0°C
    restNearTargetMinMs = 20000

Behavior:

  Condition              Result
  ---------------------- -----------------------------
  Far from target        Moderate heat pulses
  Near target            Minimum heat, extended rest
  Fast hotspot rise      Extended rest
  Safety limit reached   Heater OFF

------------------------------------------------------------------------

# Fail‑Safe Handling

Invalid temperature sentinel:

    temp = -32768

If detected:

    Heater OFF
    Fault state optional

------------------------------------------------------------------------

# Control Authority

Control decisions use exclusively:

    tempChamberC

Hotspot temperature is used only for:

-   Safety enforcement
-   Adaptive timing adjustment

UI displays:

    tempChamberC

------------------------------------------------------------------------

# Example: Silicagel Operation

Preset:

    target = 105°C
    tolerance = 2°C
    max = 110°C

Result:

Stable operating range:

    100°C … 110°C

Overshoot prevented by:

-   chamberMaxC
-   pulse scheduler
-   hotspot adaptive limiting

------------------------------------------------------------------------

# Implementation Requirements

Host must:

-   Parse STATUS frame
-   Maintain chamber and hotspot temps
-   Apply pulse scheduler
-   Apply safety layers
-   Control heater via bitmask

Client must:

-   Read ADS1115
-   Convert NTC temperatures
-   Send STATUS frame periodically

------------------------------------------------------------------------

# End of Specification

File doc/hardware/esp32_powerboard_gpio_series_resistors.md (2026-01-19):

# ESP32-WROOM ↔ PowerBoard – GPIO-Serienwiderstände (220–330 Ω)

Dieses Dokument beschreibt **vollständig und detailliert**, welche GPIO-Pins des ESP32-WROOM
mit **Serienwiderständen (typisch 220–330 Ω)** an das PowerBoard angebunden werden sollen
und **warum** dies empfohlen ist.

Grundlage ist das von dir bereitgestellte GPIO-/Channel-Mapping.

---

## 1) Empfohlene Serienwiderstände (Hauptsignale: Aktoren & UART)

| Oven | GPIO | Channel | Widerstand | Info |
|---|---|---|---:|---|
| **OVEN_FAN12V** | **GPIO32** | **PIN_CH0** | **220–330 Ω** | Digitaler Ausgang zum PowerBoard-Treiberkanal (CH0). Serienwiderstand empfohlen (Schutz & EMV). |
| **OVEN_FAN230V** | **GPIO33** | **PIN_CH1** | **220–330 Ω** | Digitaler Ausgang (CH1) zum TRIAC-/Treiberpfad. Serienwiderstand empfohlen. |
| **OVEN_FAN230V_SLOW** | **GPIO25** | **PIN_CH2** | **220–330 Ω** | Digitaler Ausgang (CH2) zum TRIAC-/Treiberpfad. Serienwiderstand empfohlen. |
| **OVEN_LAMP** | **GPIO26** | **PIN_CH3** | **220–330 Ω** | Digitaler Ausgang (CH3) zum Treiberpfad. Serienwiderstand empfohlen. |
| **OVEN_SILICAT_MOTOR** | **GPIO27** | **PIN_CH4** | **220–330 Ω** | Digitaler Ausgang (CH4) zum TRIAC-/Motor-Treiberpfad. Serienwiderstand empfohlen. |
| **OVEN_HEATER** | **GPIO12** | **PIN_CH6** | **220–330 Ω** | Digitaler Ausgang (CH6) zum Relais-Treiberpfad (Heater). Serienwiderstand empfohlen. |
| **UART_TX (Client → PowerBoard)** | **GPIO17** | **TX2** | **220–330 Ω** | UART-TX vom ESP32 zum PowerBoard-RX. Sehr empfohlen für Signalintegrität & Schutz. |
| **UART_RX (PowerBoard → Client)** | **GPIO16** | **RX2** | **0–220 Ω (optional)** | UART-RX am ESP32. Standard 0 Ω; optional kleiner Serienwiderstand bei langen/noisy Leitungen. |

**Layout-Hinweis:**  
Serienwiderstände sollten **nah am ESP32-GPIO** platziert werden (Quellseite).

---

## 2) Signale, die *nicht* pauschal mit 220–330 Ω seriell ausgeführt werden

### 2.1 Door-Signal (Eingang)
| Oven | GPIO | Channel | Widerstand | Info |
|---|---|---|---:|---|
| **OVEN_DOOR_SENSOR** | **GPIO14** | **PIN_CH5** | **kein 220–330 Ω Standard** | Eingangssignal. Üblich sind Pull-up/Pull-down und ggf. RC-Filter. Serien-R eher 1–4,7 kΩ falls benötigt. |

**Typische Eingangsbeschaltung (Beispiele):**
- Pull-up: 10 kΩ nach 3,3 V (oder interner Pull-up)
- Optional RC-Filter: 1–4,7 kΩ + 10–100 nF
- Optional ESD-Schutz bei langen Leitungen

---

### 2.2 Analoge Eingänge (ADC)
| Oven | GPIO | Channel | Widerstand | Info |
|---|---|---|---:|---|
| *(ADC)* | GPIO36 | PIN_ADC0 | kein 220–330 Ω | Analogeingang. RC-Filter & Schutz gezielt auslegen. |
| *(ADC)* | GPIO39 | PIN_ADC1 | kein 220–330 Ω | Analogeingang. RC-Filter & Schutz gezielt auslegen. |
| *(ADC)* | GPIO34 | PIN_ADC2 | kein 220–330 Ω | Analogeingang. RC-Filter & Schutz gezielt auslegen. |
| *(ADC)* | GPIO35 | PIN_ADC3 | kein 220–330 Ω | Analogeingang. RC-Filter & Schutz gezielt auslegen. |

**Begründung:**  
Ein pauschaler Serienwiderstand kann die ADC-Messung verfälschen (Quellimpedanz, Sample-and-Hold).

---

### 2.3 SPI (MAX6675, optional)
| Oven | GPIO | Channel | Widerstand | Info |
|---|---|---|---:|---|
| *(MAX6675_SCK)* | GPIO18 | PIN_MAX6675_SCK | 220–330 Ω (optional) | SPI-Takt, schnelle Flanken → optional zur Dämpfung bei längeren Leitungen. |
| *(MAX6675_CS)* | GPIO5 | PIN_MAX6675_CS | 220–330 Ω (optional) | Optional bei längeren Leitungen. |
| *(MAX6675_SO / MISO)* | GPIO19 | PIN_MAX6675_SO | 0–220 Ω (optional) | Eingang am ESP32, meist 0 Ω ausreichend. |

---

## 3) Zusammenfassung – Was konkret bestücken?

### 3.1 Pflicht / Stark empfohlen
- **Alle Aktor-Steuerleitungen (MCU → PowerBoard)** mit **220–330 Ω**:  
  GPIO32, GPIO33, GPIO25, GPIO26, GPIO27, GPIO12
- **UART TX (GPIO17)** mit **220–330 Ω**

### 3.2 Optional / situationsabhängig
- **UART RX (GPIO16)**: 0 Ω Standard, optional 100–220 Ω
- **SPI SCK/CS**: optional 220–330 Ω bei längeren Leitungen

### 3.3 Nicht wie Ausgänge behandeln
- **Door Input (GPIO14)**: Pull-up + optional RC-Filter
- **ADC Inputs (GPIO36/39/34/35)**: gezielte Analogbeschaltung

---

## 4) Begründung – Warum Serienwiderstände?

### 4.1 Schutz der GPIOs
Serienwiderstände begrenzen den Strom bei:
- Kurzschluss gegen GND oder 3,3 V
- Fehlverdrahtung / Steckfehler
- Treiber-Kollisionen (MCU treibt gegen externen Treiber)

### 4.2 Bessere Signalqualität
GPIOs haben sehr schnelle Flanken. Leitungen wirken als Übertragungsleitungen:
- Überschwingen (Ringing)
- Fehltrigger an Treiber- oder Gate-Eingängen

Der Serienwiderstand dämpft diese Effekte zuverlässig.

### 4.3 EMV-Verbesserung
Gedämpfte Flanken → weniger hochfrequente Störenergie:
- geringere Abstrahlung
- weniger Einkopplung in Nachbarleitungen (z. B. UART)

### 4.4 Robustere Treiberansteuerung
Optokoppler, Transistorbasen und Gate-Netze verursachen Stromspitzen.
Der Serienwiderstand reduziert diese und erhöht die Robustheit.

### 4.5 Stabilere UART-Kommunikation
UART ist empfindlich auf Störungen rund um Start-/Stop-Bits.
Ein Serienwiderstand am **TX** ist eine einfache und sehr effektive Maßnahme.

---

## 5) Referenz: GPIO-Zuordnung (aus Projekt)

- OVEN_FAN12V = PIN_CH0 = GPIO32  
- OVEN_FAN230V = PIN_CH1 = GPIO33  
- OVEN_FAN230V_SLOW = PIN_CH2 = GPIO25  
- OVEN_LAMP = PIN_CH3 = GPIO26  
- OVEN_SILICAT_MOTOR = PIN_CH4 = GPIO27  
- OVEN_DOOR_SENSOR = PIN_CH5 = GPIO14  
- OVEN_HEATER = PIN_CH6 = GPIO12  

- UART: CLIENT_RX2 = GPIO16, CLIENT_TX2 = GPIO17

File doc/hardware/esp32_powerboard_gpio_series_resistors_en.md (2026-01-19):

# ESP32-WROOM ↔ PowerBoard – GPIO Series Resistors (220–330 Ω)

This document summarizes which ESP32-WROOM GPIO signals should be connected to the PowerBoard **with series resistors**
(typically **220–330 Ω**), and why this is recommended.

The mapping is based on the GPIO list you provided (ESP32-WROOM "Client" side).

---

## 1) Recommended Series Resistors (Main Control & UART)

| Oven | GPIO | Channel | Widerstand | Info |
|---|---|---|---:|---|
| **OVEN_FAN12V** | **GPIO32** | **PIN_CH0** | **220–330 Ω** | Digital output to PowerBoard driver channel (CH0). Series resistor recommended for protection and EMI reduction. |
| **OVEN_FAN230V** | **GPIO33** | **PIN_CH1** | **220–330 Ω** | Digital output (CH1) to TRIAC/driver path. Series resistor recommended. |
| **OVEN_FAN230V_SLOW** | **GPIO25** | **PIN_CH2** | **220–330 Ω** | Digital output (CH2) to TRIAC/driver path. Series resistor recommended. |
| **OVEN_LAMP** | **GPIO26** | **PIN_CH3** | **220–330 Ω** | Digital output (CH3) to driver path. Series resistor recommended. |
| **OVEN_SILICAT_MOTOR** | **GPIO27** | **PIN_CH4** | **220–330 Ω** | Digital output (CH4) to motor TRIAC/driver path. Series resistor recommended. |
| **OVEN_HEATER** | **GPIO12** | **PIN_CH6** | **220–330 Ω** | Digital output (CH6) to relay driver path (heater relay). Series resistor recommended. |
| **UART_TX (Client → PowerBoard)** | **GPIO17** | **TX2** | **220–330 Ω** | UART TX from ESP32 to PowerBoard RX. Strongly recommended to improve signal integrity and protect against wiring faults. |
| **UART_RX (PowerBoard → Client)** | **GPIO16** | **RX2** | **0–220 Ω (optional)** | UART RX at ESP32. Usually **0 Ω** is fine; **100–220 Ω** can help on long/noisy harnesses (optional). |

### Practical placement note
- Place the **series resistor close to the ESP32 GPIO pin** (driver side).  
  This improves protection and reduces ringing by damping the fast edge right at the source.

---

## 2) Signals that are *not* typically implemented with 220–330 Ω series resistors

These pins are present in your list, but they are usually treated differently.

### 2.1 Door input (OVEN_DOOR_SENSOR)
| Oven | GPIO | Channel | Widerstand | Info |
|---|---|---|---:|---|
| **OVEN_DOOR_SENSOR** | **GPIO14** | **PIN_CH5** | **no 220–330 Ω series (default)** | Door sensor is an **input**. Typical measures are **pull-up/pull-down**, optional **RC filtering**, and optionally a **small series resistor** (e.g. 1–4.7 kΩ) if you explicitly want ESD/current limiting on the input. |

**Typical input conditioning (examples):**
- Pull-up: 10 kΩ to 3.3 V (or internal pull-up if reliable)
- Optional RC filter: 1–4.7 kΩ series + 10–100 nF to GND (debounce/noise)
- ESD protection diode/clamp if the harness is long and exposed

> Note: A 220–330 Ω series resistor on an input is *not wrong*, but it is not the “standard default” measure like it is for **outputs** and **UART TX**. For noisy door lines, an RC filter is usually the more effective tool.

### 2.2 Analog inputs (ADC)
| Oven | GPIO | Channel | Widerstand | Info |
|---|---|---|---:|---|
| *(analog)* | GPIO36 | PIN_ADC0 | no 220–330 Ω series (default) | ADC input. Prefer RC filter and proper source impedance management. |
| *(analog)* | GPIO39 | PIN_ADC1 | no 220–330 Ω series (default) | ADC input. Prefer RC filter and proper source impedance management. |
| *(analog)* | GPIO34 | PIN_ADC2 | no 220–330 Ω series (default) | ADC input. Prefer RC filter and proper source impedance management. |
| *(analog)* | GPIO35 | PIN_ADC3 | no 220–330 Ω series (default) | ADC input. Prefer RC filter and proper source impedance management. |

**Why not “blindly” 220–330 Ω on ADC?**
- ADC readings can be affected by the source impedance and the sampling capacitor behavior.
- If you need protection/noise filtering, use a **defined RC filter** and confirm it against sampling requirements.

### 2.3 SPI (MAX6675) – optional depending on wiring length
You listed MAX6675 pins as an example (SCK=GPIO18, CS=GPIO5, SO/MISO=GPIO19).

| Oven | GPIO | Channel | Widerstand | Info |
|---|---|---|---:|---|
| *(MAX6675_SCK)* | GPIO18 | PIN_MAX6675_SCK | 220–330 Ω (optional) | SPI clock has fast edges; series resistor can reduce EMI/ringing on longer wires. |
| *(MAX6675_CS)* | GPIO5 | PIN_MAX6675_CS | 220–330 Ω (optional) | Optional for long harnesses; improves edge damping and protection. |
| *(MAX6675_SO / MISO)* | GPIO19 | PIN_MAX6675_SO | 0–220 Ω (optional) | Input to ESP32. Usually 0 Ω is fine; small resistor can help if ringing occurs. |

---

## 3) Summary (What to implement)

### 3.1 “Must / Strongly Recommended”
- **All PowerBoard control outputs**:  
  **GPIO32, GPIO33, GPIO25, GPIO26, GPIO27, GPIO12 → 220–330 Ω series**
- **UART TX to PowerBoard**:  
  **GPIO17 (TX2) → 220–330 Ω series**

### 3.2 “Optional / Situation-dependent”
- **UART RX from PowerBoard**:  
  **GPIO16 (RX2) → 0 Ω default, 100–220 Ω optional**
- **SPI SCK/CS** (if MAX6675 is wired via harness / longer distance):  
  **GPIO18, GPIO5 → 220–330 Ω optional**
- **SPI MISO**:  
  **GPIO19 → 0 Ω default, small series optional**

### 3.3 “Do not treat like outputs”
- **Door sensor input (GPIO14)**: prefer pull-up + optional RC filter
- **ADC inputs (GPIO36/39/34/35)**: prefer RC filter/protection designed for ADC behavior

---

## 4) Why series resistors are necessary / recommended

Series resistors (220–330 Ω) between MCU GPIOs and an external board/harness are a proven best practice for robustness.

### 4.1 GPIO protection (short circuits, wiring mistakes, contention)
In real builds, failures happen:
- A pin can be accidentally shorted to GND or 3.3 V,
- a connector can be misaligned,
- an external stage may momentarily drive a line when the MCU also drives it.

A series resistor limits the instantaneous current so the GPIO and/or the external stage is less likely to be damaged.

### 4.2 Signal integrity (damping fast edges, reducing ringing/overshoot)
GPIO outputs have fast edges; a cable/harness behaves like a transmission line:
- inductance and capacitance cause **ringing** and **overshoot**,
- this can lead to false switching (especially on sensitive driver inputs),
- it increases EMI emissions.

A 220–330 Ω resistor plus input capacitance creates a controlled edge and damps ringing.

### 4.3 EMI reduction (practical EMC improvement)
Lower edge rate = lower high-frequency energy:
- fewer radiated emissions,
- fewer conducted disturbances on the harness,
- less chance to upset adjacent lines (e.g., UART lines near actuator controls).

### 4.4 External driver input behavior (optos/transistors/triac gates)
PowerBoard inputs often go into:
- optocoupler LEDs,
- transistor bases,
- gate networks for MOSFETs / TRIAC gate drive.

These structures can draw current spikes during transitions. The series resistor reduces peaks and makes the system more tolerant.

### 4.5 UART stability (especially TX)
UART decoding is sensitive around thresholds on the start bit:
- ringing/overshoot can create extra edges,
- long harnesses and ground bounce make this worse.

A series resistor at **TX** is one of the simplest ways to increase UART robustness.

---

## 5) Implementation hints (practical)

- Put the resistor **close to the ESP32** (source side).
- Use one resistor **per line** (do not share).
- Prefer 220 Ω if you need slightly faster edges; prefer 330 Ω if wiring is long/noisy.
- If a line is particularly noisy, consider:
  - twisted pair with GND reference,
  - adding a defined RC filter (inputs),
  - improving grounding and return paths.

---

## 6) Reference: Provided GPIO mapping (for traceability)

- OVEN_FAN12V = PIN_CH0 = GPIO32  
- OVEN_FAN230V = PIN_CH1 = GPIO33  
- OVEN_FAN230V_SLOW = PIN_CH2 = GPIO25  
- OVEN_LAMP = PIN_CH3 = GPIO26  
- OVEN_SILICAT_MOTOR = PIN_CH4 = GPIO27  
- OVEN_DOOR_SENSOR = PIN_CH5 = GPIO14  
- OVEN_HEATER = PIN_CH6 = GPIO12  

- Serial2: CLIENT_RX2 = GPIO16, CLIENT_TX2 = GPIO17

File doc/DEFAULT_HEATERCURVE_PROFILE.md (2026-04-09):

# Default HeaterCurve Profile

Stand: aktueller Default-Code-Stand

Hinweis:

- Diese Tabelle zeigt die aktuellen Default-Werte aus dem Source-Code.
- `hysteresis`, `approachBand`, `holdBand` und `overshootCap` koennen zur Laufzeit ueber `host_parameters` ueberschrieben werden.
- Die Tabelle beschreibt also den Default-Fallback bzw. Initialzustand im Code.

| Parameter | `LOW_45C` | `MID_60C` | `HIGH_80C` | `SILICA_100C` |
|---|---:|---:|---:|---:|
| MaterialClass | `FILAMENT` | `FILAMENT` | `FILAMENT` | `SILICA` |
| Typische Presets | `PLA`, `TPU`, `PVA`, `BVOH` | `PETG`, `HIPS`, `PP` | `ABS`, `ASA`, `PA`, `PC`, `PPS` | `SILICA` |
| Preset-Temperaturbereich | `42.5..52.5°C` | `55.0..65.0°C` | `70.0..85.0°C` | `105.0°C` |
| Hysterese | `1.5°C` | `1.5°C` | `1.5°C` | `2.5°C` |
| Approach-Band | `10.0°C` | `10.0°C` | `10.0°C` | `10.0°C` |
| Hold-Band | `4.0°C` | `4.0°C` | `4.0°C` | `2.5°C` |
| Overshoot-Cap | `+2.0°C` | `+2.0°C` | `+2.0°C` | `+3.0°C` |
| Chamber-Max | `120.0°C` | `120.0°C` | `120.0°C` | `120.0°C` |
| Hotspot-Max | `140.0°C` | `140.0°C` | `140.0°C` | `140.0°C` |
| First Pulse Max | `10000 ms` | `11000 ms` | `12000 ms` | `45000 ms` |
| Bulk Pulse Max | `10000 ms` | `10000 ms` | `10000 ms` | `18000 ms` |
| Approach Pulse Max | `7000 ms` | `7000 ms` | `7000 ms` | `12000 ms` |
| Hold Pulse Max | `6000 ms` | `6000 ms` | `6000 ms` | `8000 ms` |
| First Soak | `45000 ms` | `45000 ms` | `45000 ms` | `60000 ms` |
| Reheat Soak | `30000 ms` | `30000 ms` | `30000 ms` | `35000 ms` |
| Safety Soak | `90000 ms` | `90000 ms` | `90000 ms` | `120000 ms` |
| Bulk Enable Below Target | `20.0°C` | `20.0°C` | `20.0°C` | `25.0°C` |
| Approach Enable Below Target | `10.0°C` | `10.0°C` | `10.0°C` | `12.0°C` |
| Reheat Enable Below Target | `3.0°C` | `3.0°C` | `2.0°C` | `4.0°C` |
| Force-Off Before Target | `1.0°C` | `1.0°C` | `1.0°C` | `1.0°C` |
| First-Pulse Force-Off Before Target | `2.0°C` | `2.0°C` | `2.0°C` | `2.0°C` |
| Hotspot Reheat Block | `+5.0°C` | `+5.0°C` | `+5.0°C` | `n/a` |
| Hotspot Force-Off | `+10.0°C` | `+10.0°C` | `+10.0°C` | `n/a` |
| Fan Min Switch | `5000 ms` | `5000 ms` | `5000 ms` | `n/a` |
| Fan Fast After Heat | `12000 ms` | `12000 ms` | `12000 ms` | `n/a` |
| Resume Soak | `12000 ms` | `12000 ms` | `12000 ms` | `n/a` |
| Resume Min Soak | `5000 ms` | `5000 ms` | `5000 ms` | `n/a` |
| Resume Hot-Target Soak | `7000 ms` | `7000 ms` | `7000 ms` | `n/a` |
| Resume Short Pulse | `6000 ms` | `6000 ms` | `6000 ms` | `n/a` |
| Resume Long Pulse | `8000 ms` | `8000 ms` | `8000 ms` | `n/a` |

## Kurzfazit

- `LOW_45C` und `MID_60C` unterscheiden sich aktuell nur leicht.
- `HIGH_80C` hat bereits frueheres Reheat als die beiden darunter.
- `SILICA_100C` ist klar als eigenes High-Temp-Profil aufgebaut.

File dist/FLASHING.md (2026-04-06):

# Flashing

Dieses Release enthaelt pro ESP zwei relevante Artefaktarten:

- `*_firmware.elf`: Debug-/Analyse-Artefakt aus dem Build
- `*_flash.bin`: zusammengefuehrte Flash-Datei fuer direktes Schreiben auf den ESP

Empfohlene Flash-Offets der Einzeldateien:

- Host ESP32-S3:
  - `0x0000` `bootloader.bin`
  - `0x8000` `partitions.bin`
  - `0xE000` `boot_app0.bin`
  - `0x10000` `firmware.bin`

- Client ESP32:
  - `0x1000` `bootloader.bin`
  - `0x8000` `partitions.bin`
  - `0xE000` `boot_app0.bin`
  - `0x10000` `firmware.bin`

Alternativ direkt die jeweilige `*_flash.bin` verwenden.

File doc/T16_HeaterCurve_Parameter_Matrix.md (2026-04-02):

# T16 HeaterCurve Parameter Matrix

Stand: aktueller Source-Stand nach `T16_Phase_4.1`

## Profil-Zuordnung

- `LOW_45C`: niedrige Filament-Trocknungstemperaturen, z. B. PLA/TPU/BVOH/PVA
- `MID_60C`: mittlere Filament-Trocknungstemperaturen, z. B. PETG/HIPS/PP
- `HIGH_80C`: hohe Filament-Trocknungstemperaturen, z. B. ABS/ASA/PA/PC/PPS
- `SILICA_100C`: Silicagel-Trocknung im Bereich um 100 C

## Parameter-Tabelle

| Parameter | Info | `LOW_45C` | `MID_60C` | `HIGH_80C` | `SILICA_100C` |
|---|---|---:|---:|---:|---:|
| `materialClass` | Grobe Materialgruppe fuer bestehende Speziallogik im Host. | `FILAMENT` | `FILAMENT` | `FILAMENT` | `SILICA` |
| `hysteresisC` | Hysterese im `HOLD`-Bereich der Basis-Policy. Bestimmt, wie weit die Chamber unter Target fallen darf, bevor wieder geheizt wird. | `1.5 C` | `1.5 C` | `1.5 C` | `2.5 C` |
| `approachBandC` | Abstand zum Target, ab dem von `BULK_HEAT` nach `APPROACH` gewechselt wird. | `10.0 C` | `10.0 C` | `10.0 C` | `10.0 C` |
| `holdBandC` | Abstand zum Target, ab dem in den `HOLD`-Bereich gewechselt wird. | `4.0 C` | `4.0 C` | `4.0 C` | `2.5 C` |
| `targetOvershootCapC` | Harte Host-Safety-Grenze relativ zum Target. Wird sie ueberschritten, setzt der Host `safetyCutoffActive`. | `+2.0 C` | `+2.0 C` | `+2.0 C` | `+3.0 C` |
| `chamberMaxC` | Absolute maximale Chamber-Temperatur fuer die Host-Safety. | `120.0 C` | `120.0 C` | `120.0 C` | `120.0 C` |
| `hotspotMaxC` | Absolute maximale Hotspot-Temperatur fuer die Host-Safety. | `140.0 C` | `140.0 C` | `140.0 C` | `140.0 C` |
| `firstPulseMaxMs` | Maximaldauer des allerersten Heizpulses nach Start. Begrenzt den initialen Energieeintrag. | `10000 ms` | `10000 ms` | `11000-12000 ms` | `30000 ms` |
| `bulkPulseMaxMs` | Maximaldauer eines Heizpulses im groben Aufheizbereich weit unter Target. | `10000 ms` | `10000 ms` | `10000 ms` | `18000 ms` |
| `approachPulseMaxMs` | Maximaldauer eines Heizpulses in der Annäherungsphase an das Target. | `7000 ms` | `7000 ms` | `7000 ms` | `12000 ms` |
| `holdPulseMaxMs` | Maximaldauer eines kurzen Nachheizpulses im spaeten Haltebereich. | `6000 ms` | `6000 ms` | `4000-5000 ms` | `8000 ms` |
| `firstSoakMs` | Erzwingt nach dem ersten Heizpuls eine Beobachtungs-/Abkuehlphase ohne neues Heizen. Wichtig gegen Nachlauf-Overshoot. | `45000 ms` | `45000 ms` | `45000 ms` | `90000 ms` |
| `reheatSoakMs` | Erzwingt zwischen Folgepulsen eine Pause, damit das traege System nachlaufen und ausgewertet werden kann. | `30000 ms` | `30000 ms` | `30000 ms` | `45000 ms` |
| `safetySoakMs` | Zusaetzliche Sperrzeit nach einem Safety-Ereignis, bevor wieder geheizt werden darf. | `90000 ms` | `90000 ms` | `90000 ms` | `120000 ms` |
| `bulkPulseEnableBelowTargetC` | Fehler zum Target, ab dem statt kleinerer Pulse noch ein voller Bulk-Puls erlaubt wird. | `20.0 C` | `20.0 C` | `20.0 C` | `25.0 C` |
| `approachPulseEnableBelowTargetC` | Fehler zum Target, ab dem noch ein Approach-Puls statt eines Hold-Pulses erlaubt wird. | `10.0 C` | `10.0 C` | `10.0 C` | `12.0 C` |
| `reheatEnableBelowTargetC` | Chamber muss mindestens um diesen Betrag unter Target liegen, bevor wieder geheizt werden darf. | `3.0 C` | `3.0 C` | `3.0 C` | `5.0 C` |
| `forceOffBeforeTargetC` | Direkte Abschaltreserve vor Target fuer spaetere Pulse. Verhindert, dass bei zu spaeter Abschaltung zu viel Restwaerme nachkommt. | `1.0 C` | `1.0 C` | `1.0 C` | `1.5 C` |
| `firstPulseForceOffBeforeTargetC` | Strengere Abschaltreserve fuer den allerersten Puls, um den ersten Peak zu entschaerfen. | `2.0 C` | `2.0 C` | `2.0 C` | `3.0 C` |
| `hotspotReheatBlockAboveTargetC` | Blockiert bei Filament einen neuen Heizpuls, wenn der Hotspot noch zu weit ueber dem Target liegt. | `+5.0 C` | `+5.0 C` | `+5.0 C` | `n/a` |
| `hotspotForceOffAboveTargetC` | Erzwingt bei Filament Heater-OFF, wenn der Hotspot weit ueber dem Target liegt. | `+10.0 C` | `+10.0 C` | `+10.0 C` | `n/a` |
| `fanMinSwitchMs` | Minimaler Umschaltabstand zwischen `FAN230V` und `FAN230V_SLOW` zur Schonung von Motor und Elektronik. | `5000 ms` | `5000 ms` | `5000 ms` | `n/a` |
| `fanFastAfterHeatMs` | Haelt bei Filament nach einem Heizpuls den schnellen Luefter fuer eine feste Zeit aktiv. | `12000 ms` | `12000 ms` | `12000 ms` | `n/a` |
| `waitResumeSoakMs` | Standard-Sperrzeit nach `WAIT -> RUNNING`, bevor wieder geheizt werden darf. | `12000 ms` | `12000 ms` | `12000 ms` | `n/a` |
| `waitResumeSoakMinMs` | Untergrenze fuer die Resume-Sperrzeit nach `WAIT`. | `5000 ms` | `5000 ms` | `5000 ms` | `n/a` |
| `waitResumeSoakHotTargetMs` | Kuerzere Resume-Sperrzeit fuer heissere Filament-Targets. | `7000 ms` | `7000 ms` | `7000 ms` | `n/a` |
| `waitResumePulseShortMs` | Kurzer Recovery-Puls nach `WAIT`, wenn nur wenig Temperatur zum Target fehlt. | `6000 ms` | `6000 ms` | `6000 ms` | `n/a` |
| `waitResumePulseLongMs` | Laengerer Recovery-Puls nach `WAIT`, wenn deutlich mehr Temperatur zum Target fehlt. | `8000 ms` | `8000 ms` | `8000 ms` | `n/a` |
| `waitResumeLongPulseErrorC` | Temperaturfehler, ab dem nach `WAIT` der lange Recovery-Puls verwendet wird. | `8.0 C` | `8.0 C` | `8.0 C` | `n/a` |
| `waitResumeMediumPulseErrorC` | Temperaturfehler, ab dem ein mittlerer Recovery-Puls verwendet wird. | `5.0 C` | `5.0 C` | `5.0 C` | `n/a` |
| `midTargetC` | Schwelle, ab der Filament-Targets als mittlerer/hoeherer Temperaturbereich behandelt werden. | `70.0 C` | `70.0 C` | `70.0 C` | `n/a` |
| `waitResumeHotTargetC` | Schwelle, ab der Filament-Targets als heiss betrachtet und defensiver resumiert werden. | `80.0 C` | `80.0 C` | `80.0 C` | `n/a` |
| `waitResumeLongOpenMs` | Tueroeffnungsdauer, ab der der Resume-Pfad als laengerer Unterbruch behandelt wird. | `15000 ms` | `15000 ms` | `15000 ms` | `n/a` |
| `controlStrategy` | Beschreibt die aktuell verwendete Regelidee im Host. | `bounded filament pulses + fan hysteresis` | `bounded filament pulses + fan hysteresis` | `bounded filament pulses + fan hysteresis` | `bounded silica pulses, chamber-dominated` |
| `safetyPrimarySensor` | Fuehrende Groesse fuer die Safety-Entscheidung. | `Chamber + Hotspot` | `Chamber + Hotspot` | `Chamber + Hotspot` | `Chamber primär, Hotspot als Zusatz-Cutoff` |
| `reheatDecisionBasis` | Hauptgroesse fuer die Freigabe neuer Heizpulse. | `Chamber + Hotspot-Guards` | `Chamber + Hotspot-Guards` | `Chamber + Hotspot-Guards` | `Chamber` |

## Hinweise

- `LOW_45C`, `MID_60C` und `HIGH_80C` sind architektonisch getrennt, aber fachlich noch nicht vollstaendig unterschiedlich kalibriert.
- Die erste echte spezifische Profil-Regelung wurde in `T16_Phase_4.1` fuer `SILICA_100C` eingefuehrt.
- Die Profilfeinabstimmung fuer `LOW_45C`, `MID_60C` und `HIGH_80C` ist weiterhin offen.

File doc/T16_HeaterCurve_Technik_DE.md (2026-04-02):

# T16 HeaterCurve Technik

Stand: aktueller Source-Stand nach `T16_Phase_4.1.3`

## Ziel

Diese Doku zeigt Dir, wie die HeaterCurve-Technik im Host aktuell funktioniert:

- wie ein Preset auf eine HeaterCurve gemappt wird
- welche Regelidee dahinter steckt
- welche Parameter heute schon im Code existieren
- welche Presets von welcher Curve abgedeckt werden

Das Ganze beschreibt den echten Ist-Stand im Code. Kein Wunschbild, kein Theoriepapier.

## Kurzbild

```mermaid
flowchart TD
    A["UI Preset auswählen"] --> B["Preset aus kPresets[]"]
    B --> C["HeaterCurveProfileId bestimmen"]
    C --> D["HeaterPolicy laden"]
    D --> E["RuntimeState aktualisieren"]
    E --> F["Host bekommt Chamber + Hotspot vom Client"]
    F --> G["Stage bestimmen: BULK / APPROACH / HOLD"]
    G --> H{"Profil-Typ?"}
    H -->|FILAMENT| I["bounded filament pulses"]
    H -->|SILICA_100C| J["bounded silica pulses"]
    I --> K["Heater-Intent berechnen"]
    J --> K
    K --> L["Min ON/OFF + Safety anwenden"]
    L --> M["Output-Maske an Client senden"]
    L --> N["CSV_HOST_PLOT / CSV_HOST_LOGIC loggen"]
```

## Architektur in 3 Schichten

### 1. Preset-Schicht

Hier liegt die fachliche Auswahl aus der UI:

- Name
- Trocknungstemperatur
- Dauer
- Materialklasse
- HeaterCurve-Profil
- Post-Plan

Die Presets liegen in:

- [include/oven.h](/Users/bernhardklein/workspace/arduino/esp32/FilamentSilicatDryer_480x480/include/oven.h)

### 2. HeaterCurve-Schicht

Hier wird festgelegt, welche Regelcharakteristik das Preset bekommt:

- `LOW_45C`
- `MID_60C`
- `HIGH_80C`
- `SILICA_100C`

Das Profil sagt also nicht nur "welches Material", sondern vor allem:

- wie lang ein Puls sein darf
- wann wieder nachgeheizt werden darf
- wie konservativ vor Target abgeschaltet wird
- wie Safety und Fan-Logik einwirken

### 3. Laufzeit-/Regelschicht

Zur Laufzeit entscheidet der Host mit den Telemetriedaten vom Client:

- `tempChamberC` ist die Fuehrungsgroesse
- `tempHotspotC` ist Zusatzschutz und Filament-Guard
- daraus werden Stage, Pulse, Soak-Zeiten und Safety abgeleitet

## Datenfluss

```mermaid
sequenceDiagram
    participant UI as UI/Touch
    participant Host as Host ESP32-S3
    participant Client as Client ESP32-WROOM
    participant HW as Heater/Fans/NTCs

    UI->>Host: Preset wählen + Start
    Host->>Host: Profil + Policy aktivieren
    Client->>HW: NTCs und Zustände lesen
    Client->>Host: STATUS (Chamber, Hotspot, Door, Outputs)
    Host->>Host: Stage + Intent + Safety berechnen
    Host->>Client: SET Outputs
    Client->>HW: Heater/Fans/Motor/Lamp schalten
    Host->>Host: CSV_HOST_PLOT / CSV_HOST_LOGIC ausgeben
```

## Was der Host wirklich regelt

Wichtig:

- Der Host ist die `single-source-of-truth`.
- Geregelt wird primär auf `Chamber`.
- `Hotspot` wird bei Filament als zusaetzlicher Guard genutzt.
- Bei `SILICA_100C` ist die Regelung bewusst noch staerker chamber-dominiert.

## Stages

Der Host kennt aktuell 3 Heizstufen:

- `BULK_HEAT`
  - weit weg vom Target
  - grobe Aufheizphase
- `APPROACH`
  - naehert sich dem Target
  - vorsichtiger
- `HOLD`
  - Haltebereich
  - nur noch kurze, begrenzte Nachheizpulse

Die Stage ergibt sich aus:

- `target - chamber`
- `approachBandC`
- `holdBandC`

## Grundidee der Algorithmen

### Filament

Filament arbeitet nicht mehr als offenes Dauerheizen, sondern als Pulsregler:

1. kurzer Heizpuls
2. Heater aus
3. Soak-/Beobachtungsphase
4. erst danach neue Entscheidung

Zusaetzlich greifen Guards:

- Hotspot darf Reheat blockieren
- Hotspot kann Force-Off ausloesen
- Chamber vor Target kann prädiktiv zum Abschalten fuehren
- nach `WAIT` wird konservativ resumed
- Fan wird mit Mindestschaltzeit und Fast-Phase nach Heater-Pulsen gefuehrt

### Silica

`SILICA_100C` arbeitet ebenfalls mit begrenzten Pulsen, aber mit anderer Charakteristik:

- erster Puls deutlich laenger
- Bulk-/Approach-/Hold-Pulse getrennt
- laengere Soak-Phasen
- Reheat primär nach Chamber-Fenster
- Hotspot eher als Safety-Cutoff, nicht als Fuehrungsgroesse

## Preset- und Curve-Uebersicht

| HeaterCurve | Gedachter Bereich | Presets / Beispiele | Preset-Temperaturen | Regelcharakter |
|---|---|---|---|---|
| `LOW_45C` | niedrige Filament-Trocknung | `PLA`, `TPU`, `Spec-BVOH`, `Spec-PVA`, `Spec-TPU 82A`, `Spec-WOOD-Composite` | `42.5°C .. 52.5°C` | vorsichtig, kurze bis mittlere Pulse, Fokus auf Overshoot-Vermeidung |
| `MID_60C` | mittlere Filament-Trocknung | `PETG`, `Spec-HIPS`, `Spec-PETG-HF`, `Spec-PLA-CF`, `Spec-PP` | `55.0°C .. 65.0°C` | etwas kraeftiger als `LOW_45C`, weiterhin filament-sicher |
| `HIGH_80C` | hohe Filament-Trocknung | `ABS`, `ASA`, `Spec-ASA-CF`, `Spec-PA`, `Spec-PC`, `Spec-PPS`, `Spec-PVDF-PPSU` | `70.0°C .. 85.0°C` | frueheres Reheat und staerkere Hold-Pulse als bei `MID_60C` |
| `SILICA_100C` | Silicagel trocknen | `SILICA` | `105.0°C` | bounded high-temp pulses, chamber-dominiert, konservative Safety |

## Welche Presets heute wohin gemappt sind

| HeaterCurve | Presets |
|---|---|
| `LOW_45C` | `CUSTOM`, `PLA`, `TPU`, `Spec-BVOH`, `Spec-PLA-WoodMetal`, `Spec-PVA`, `Spec-TPU 82A`, `Spec-WOOD-Composite` |
| `MID_60C` | `PETG`, `Spec-HIPS`, `Spec-PETG-HF`, `Spec-PLA-CF`, `Spec-PLA-HT`, `Spec-PP`, `Spec-PP-GF` |
| `HIGH_80C` | `ABS`, `ASA`, `Spec-ASA-CF`, `Spec-PA(CF,PET,PH*)`, `Spec-PC(CF/FR)`, `Spec-PC-ABS`, `Spec-PET-CF`, `Spec-PETG-CF`, `Spec-POM`, `Spec-PPS(+CF)`, `Spec-PVDF-PPSU` |
| `SILICA_100C` | `SILICA` |

## Safety-Logik

Der Host schaltet den Heater ab, wenn eine dieser Bedingungen greift:

- Tür offen
- `Hotspot >= hotspotMaxC`
- `Chamber >= chamberMaxC`
- `Chamber >= target + targetOvershootCapC`

Bei Filament kommt zusaetzlich im Regler selbst dazu:

- Hotspot-Force-Off
- Hotspot-Reheat-Block
- prädiktives Abschalten vor Target

## WAIT / Door-Verhalten

Wenn die Tür während `RUNNING` geöffnet wird:

- der Host geht in `WAIT`
- Heater aus
- nach manuellem Fortsetzen wird nicht wie Kaltstart resumed
- stattdessen:
  - Resume-Soak
  - kurzer oder mittlerer Resume-Puls
  - Zieltemperatur und Unterbruchdauer fliessen ein

## Fan-Verhalten

Bei Filament:

- nach einem Heizpuls wird `FAN230V` für eine feste Zeit bevorzugt
- Umschalten zwischen `FAN230V` und `FAN230V_SLOW` hat eine Mindestschaltzeit
- Ziel: bessere Durchmischung ohne hektisches Umschalten

Bei Silica:

- aktuell keine eigene komplexe Fan-Hysterese wie bei Filament
- Fokus liegt erst einmal auf stabilen bounded pulses

## Parameter-Matrix

| Parameter | Info | `LOW_45C` | `MID_60C` | `HIGH_80C` | `SILICA_100C` |
|---|---|---:|---:|---:|---:|
| `materialClass` | Grobe Materialgruppe fuer bestehende Speziallogik im Host. | `FILAMENT` | `FILAMENT` | `FILAMENT` | `SILICA` |
| `hysteresisC` | Hysterese im `HOLD`-Bereich der Basis-Policy. Bestimmt, wie weit die Chamber unter Target fallen darf, bevor wieder geheizt wird. | `1.5 C` | `1.5 C` | `1.5 C` | `2.5 C` |
| `approachBandC` | Abstand zum Target, ab dem von `BULK_HEAT` nach `APPROACH` gewechselt wird. | `10.0 C` | `10.0 C` | `10.0 C` | `10.0 C` |
| `holdBandC` | Abstand zum Target, ab dem in den `HOLD`-Bereich gewechselt wird. | `4.0 C` | `4.0 C` | `4.0 C` | `2.5 C` |
| `targetOvershootCapC` | Harte Host-Safety-Grenze relativ zum Target. Wird sie ueberschritten, setzt der Host `safetyCutoffActive`. | `+2.0 C` | `+2.0 C` | `+2.0 C` | `+3.0 C` |
| `chamberMaxC` | Absolute maximale Chamber-Temperatur fuer die Host-Safety. | `120.0 C` | `120.0 C` | `120.0 C` | `120.0 C` |
| `hotspotMaxC` | Absolute maximale Hotspot-Temperatur fuer die Host-Safety. | `140.0 C` | `140.0 C` | `140.0 C` | `140.0 C` |
| `firstPulseMaxMs` | Maximaldauer des allerersten Heizpulses nach Start. Begrenzt den initialen Energieeintrag. | `10000 ms` | `11000 ms` | `12000 ms` | `45000 ms` |
| `bulkPulseMaxMs` | Maximaldauer eines Heizpulses im groben Aufheizbereich weit unter Target. | `10000 ms` | `10000 ms` | `10000 ms` | `18000 ms` |
| `approachPulseMaxMs` | Maximaldauer eines Heizpulses in der Annäherungsphase an das Target. | `7000 ms` | `7000 ms` | `7000 ms` | `12000 ms` |
| `holdPulseMaxMs` | Maximaldauer eines kurzen Nachheizpulses im spaeten Haltebereich. | `6000 ms` | `6000 ms` | `6000 ms` | `8000 ms` |
| `firstSoakMs` | Erzwingt nach dem ersten Heizpuls eine Beobachtungs-/Abkuehlphase ohne neues Heizen. Wichtig gegen Nachlauf-Overshoot. | `45000 ms` | `45000 ms` | `45000 ms` | `60000 ms` |
| `reheatSoakMs` | Erzwingt zwischen Folgepulsen eine Pause, damit das traege System nachlaufen und ausgewertet werden kann. | `30000 ms` | `30000 ms` | `30000 ms` | `35000 ms` |
| `safetySoakMs` | Zusaetzliche Sperrzeit nach einem Safety-Ereignis, bevor wieder geheizt werden darf. | `90000 ms` | `90000 ms` | `90000 ms` | `120000 ms` |
| `bulkPulseEnableBelowTargetC` | Fehler zum Target, ab dem statt kleinerer Pulse noch ein voller Bulk-Puls erlaubt wird. | `20.0 C` | `20.0 C` | `20.0 C` | `25.0 C` |
| `approachPulseEnableBelowTargetC` | Fehler zum Target, ab dem noch ein Approach-Puls statt eines Hold-Pulses erlaubt wird. | `10.0 C` | `10.0 C` | `10.0 C` | `12.0 C` |
| `reheatEnableBelowTargetC` | Chamber muss mindestens um diesen Betrag unter Target liegen, bevor wieder geheizt werden darf. | `3.0 C` | `3.0 C` | `2.0 C` | `4.0 C` |
| `forceOffBeforeTargetC` | Direkte Abschaltreserve vor Target fuer spaetere Pulse. Verhindert, dass bei zu spaeter Abschaltung zu viel Restwaerme nachkommt. | `1.0 C` | `1.0 C` | `1.0 C` | `1.0 C` |
| `firstPulseForceOffBeforeTargetC` | Strengere Abschaltreserve fuer den allerersten Puls, um den ersten Peak zu entschaerfen. | `2.0 C` | `2.0 C` | `2.0 C` | `2.0 C` |
| `hotspotReheatBlockAboveTargetC` | Blockiert bei Filament einen neuen Heizpuls, wenn der Hotspot noch zu weit ueber dem Target liegt. | `+5.0 C` | `+5.0 C` | `+5.0 C` | `n/a` |
| `hotspotForceOffAboveTargetC` | Erzwingt bei Filament Heater-OFF, wenn der Hotspot weit ueber dem Target liegt. | `+10.0 C` | `+10.0 C` | `+10.0 C` | `n/a` |
| `fanMinSwitchMs` | Minimaler Umschaltabstand zwischen `FAN230V` und `FAN230V_SLOW` zur Schonung von Motor und Elektronik. | `5000 ms` | `5000 ms` | `5000 ms` | `n/a` |
| `fanFastAfterHeatMs` | Haelt bei Filament nach einem Heizpuls den schnellen Luefter fuer eine feste Zeit aktiv. | `12000 ms` | `12000 ms` | `12000 ms` | `n/a` |
| `waitResumeSoakMs` | Standard-Sperrzeit nach `WAIT -> RUNNING`, bevor wieder geheizt werden darf. | `12000 ms` | `12000 ms` | `12000 ms` | `n/a` |
| `waitResumeSoakMinMs` | Untergrenze fuer die Resume-Sperrzeit nach `WAIT`. | `5000 ms` | `5000 ms` | `5000 ms` | `n/a` |
| `waitResumeSoakHotTargetMs` | Kuerzere Resume-Sperrzeit fuer heissere Filament-Targets. | `7000 ms` | `7000 ms` | `7000 ms` | `n/a` |
| `waitResumePulseShortMs` | Kurzer Recovery-Puls nach `WAIT`, wenn nur wenig Temperatur zum Target fehlt. | `6000 ms` | `6000 ms` | `6000 ms` | `n/a` |
| `waitResumePulseLongMs` | Laengerer Recovery-Puls nach `WAIT`, wenn deutlich mehr Temperatur zum Target fehlt. | `8000 ms` | `8000 ms` | `8000 ms` | `n/a` |
| `waitResumeLongPulseErrorC` | Temperaturfehler, ab dem nach `WAIT` der lange Recovery-Puls verwendet wird. | `8.0 C` | `8.0 C` | `8.0 C` | `n/a` |
| `waitResumeMediumPulseErrorC` | Temperaturfehler, ab dem ein mittlerer Recovery-Puls verwendet wird. | `5.0 C` | `5.0 C` | `5.0 C` | `n/a` |
| `midTargetC` | Schwelle, ab der Filament-Targets als mittlerer/hoeherer Temperaturbereich behandelt werden. | `70.0 C` | `70.0 C` | `70.0 C` | `n/a` |
| `waitResumeHotTargetC` | Schwelle, ab der Filament-Targets als heiss betrachtet und defensiver resumiert werden. | `80.0 C` | `80.0 C` | `80.0 C` | `n/a` |
| `waitResumeLongOpenMs` | Tueroeffnungsdauer, ab der der Resume-Pfad als laengerer Unterbruch behandelt wird. | `15000 ms` | `15000 ms` | `15000 ms` | `n/a` |
| `controlStrategy` | Beschreibt die aktuell verwendete Regelidee im Host. | `bounded filament pulses + fan hysteresis` | `bounded filament pulses + fan hysteresis` | `bounded filament pulses + fan hysteresis` | `bounded silica pulses, chamber-dominated` |
| `safetyPrimarySensor` | Fuehrende Groesse fuer die Safety-Entscheidung. | `Chamber + Hotspot` | `Chamber + Hotspot` | `Chamber + Hotspot` | `Chamber primär, Hotspot als Zusatz-Cutoff` |
| `reheatDecisionBasis` | Hauptgroesse fuer die Freigabe neuer Heizpulse. | `Chamber + Hotspot-Guards` | `Chamber + Hotspot-Guards` | `Chamber + Hotspot-Guards` | `Chamber` |

## Was heute schon gut funktioniert

- klare Preset-zu-Profil-Zuordnung
- bounded pulses statt offener Dauerheizung
- gute Trennung zwischen Filament und `SILICA_100C`
- Resume-Pfad nach `WAIT`
- Logging mit `CSV_HOST_PLOT`, `CSV_HOST_LOGIC`, `CSV_CLIENT_PLOT`, `CSV_CLIENT_LOGIC`

## Wo noch Luft drin ist

- `LOW_45C` kann noch etwas sauberer um den ersten Peak werden
- `LOW_45C`, `MID_60C` und `HIGH_80C` sind fachlich getrennt, aber noch nicht bis ins Letzte auskalibriert
- Hotspot-NTC ist im High-Temp-Bereich weiterhin nur begrenzt belastbar
- NTC-Kurven koennen spaeter empirisch noch verbessert werden

## Kurzfazit

Die HeaterCurve-Technik ist aktuell kein starres Thermostat mehr, sondern ein profilgesteuerter Pulsregler mit Safety-, Soak- und Resume-Logik.

Der wichtigste Punkt dabei:

- Das Preset bestimmt nicht nur die Zieltemperatur.
- Das Preset bestimmt auch, wie der Ofen thermisch dorthin arbeitet.

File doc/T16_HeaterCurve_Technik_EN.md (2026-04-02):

# T16 HeaterCurve Technology

Status: current source state after `T16_Phase_4.1.3`

## Goal

This document explains how the current HeaterCurve system works in the host:

- how a preset is mapped to a HeaterCurve
- which control idea is used
- which parameters already exist in code
- which presets are covered by which curve

This is the real implementation state. No theory paper, no future concept.

## Quick overview

```mermaid
flowchart TD
    A["Select preset in UI"] --> B["Preset from kPresets[]"]
    B --> C["Resolve HeaterCurveProfileId"]
    C --> D["Load HeaterPolicy"]
    D --> E["Update runtimeState"]
    E --> F["Host receives Chamber + Hotspot from client"]
    F --> G["Determine stage: BULK / APPROACH / HOLD"]
    G --> H{"Profile type?"}
    H -->|FILAMENT| I["bounded filament pulses"]
    H -->|SILICA_100C| J["bounded silica pulses"]
    I --> K["Compute heater intent"]
    J --> K
    K --> L["Apply min ON/OFF + safety"]
    L --> M["Send output mask to client"]
    L --> N["Emit CSV_HOST_PLOT / CSV_HOST_LOGIC"]
```

## Architecture in 3 layers

### 1. Preset layer

This is the functional selection from the UI:

- name
- drying temperature
- duration
- material class
- heater curve profile
- post plan

The presets are defined in:

- [include/oven.h](/Users/bernhardklein/workspace/arduino/esp32/FilamentSilicatDryer_480x480/include/oven.h)

### 2. HeaterCurve layer

This decides which control characteristic is used:

- `LOW_45C`
- `MID_60C`
- `HIGH_80C`
- `SILICA_100C`

So the profile does not only mean "what material", it also means:

- how long a pulse may run
- when reheating is allowed again
- how early the host forces heater off before target
- how safety and fan behavior are applied

### 3. Runtime / control layer

At runtime the host decides with the telemetry from the client:

- `tempChamberC` is the main control value
- `tempHotspotC` is extra protection and a filament guard
- stage, pulses, soak times and safety are derived from that

## Data flow

```mermaid
sequenceDiagram
    participant UI as UI/Touch
    participant Host as Host ESP32-S3
    participant Client as Client ESP32-WROOM
    participant HW as Heater/Fans/NTCs

    UI->>Host: Select preset + start
    Host->>Host: Activate profile + policy
    Client->>HW: Read NTCs and digital states
    Client->>Host: STATUS (Chamber, Hotspot, Door, Outputs)
    Host->>Host: Compute stage + intent + safety
    Host->>Client: SET outputs
    Client->>HW: Switch heater/fans/motor/lamp
    Host->>Host: Emit CSV_HOST_PLOT / CSV_HOST_LOGIC
```

## What the host really controls

Important:

- The host is the `single-source-of-truth`.
- Control is primarily based on `Chamber`.
- `Hotspot` is used as an extra guard for filament.
- For `SILICA_100C`, control is deliberately even more chamber-dominated.

## Stages

The host currently uses 3 heating stages:

- `BULK_HEAT`
  - far away from target
  - coarse warm-up
- `APPROACH`
  - getting closer to target
  - more careful
- `HOLD`
  - maintenance band
  - only short bounded reheat pulses

The stage is derived from:

- `target - chamber`
- `approachBandC`
- `holdBandC`

## Core control idea

### Filament

Filament is no longer open continuous heating. It is a pulse controller:

1. short heating pulse
2. heater off
3. soak / observation phase
4. only then a new decision

Additional guards:

- hotspot may block reheating
- hotspot may force heater off
- chamber can trigger predictive shutoff before target
- resume after `WAIT` is conservative
- fan uses minimum switching time and a fast phase after heater pulses

### Silica

`SILICA_100C` also uses bounded pulses, but with a different profile:

- much longer first pulse
- separate bulk / approach / hold pulses
- longer soak phases
- reheating mainly based on chamber window
- hotspot mainly used as a safety cutoff, not as the leading control value

## Preset and curve overview

| HeaterCurve | Intended range | Presets / examples | Preset temperatures | Control character |
|---|---|---|---|---|
| `LOW_45C` | low filament drying temperatures | `PLA`, `TPU`, `Spec-BVOH`, `Spec-PVA`, `Spec-TPU 82A`, `Spec-WOOD-Composite` | `42.5°C .. 52.5°C` | careful, short to medium pulses, focused on avoiding overshoot |
| `MID_60C` | medium filament drying temperatures | `PETG`, `Spec-HIPS`, `Spec-PETG-HF`, `Spec-PLA-CF`, `Spec-PP` | `55.0°C .. 65.0°C` | stronger than `LOW_45C`, still filament-safe |
| `HIGH_80C` | high filament drying temperatures | `ABS`, `ASA`, `Spec-ASA-CF`, `Spec-PA`, `Spec-PC`, `Spec-PPS`, `Spec-PVDF-PPSU` | `70.0°C .. 85.0°C` | earlier reheating and stronger hold pulses than `MID_60C` |
| `SILICA_100C` | silica drying | `SILICA` | `105.0°C` | bounded high-temp pulses, chamber-dominated, conservative safety |

## Current preset mapping

| HeaterCurve | Presets |
|---|---|
| `LOW_45C` | `CUSTOM`, `PLA`, `TPU`, `Spec-BVOH`, `Spec-PLA-WoodMetal`, `Spec-PVA`, `Spec-TPU 82A`, `Spec-WOOD-Composite` |
| `MID_60C` | `PETG`, `Spec-HIPS`, `Spec-PETG-HF`, `Spec-PLA-CF`, `Spec-PLA-HT`, `Spec-PP`, `Spec-PP-GF` |
| `HIGH_80C` | `ABS`, `ASA`, `Spec-ASA-CF`, `Spec-PA(CF,PET,PH*)`, `Spec-PC(CF/FR)`, `Spec-PC-ABS`, `Spec-PET-CF`, `Spec-PETG-CF`, `Spec-POM`, `Spec-PPS(+CF)`, `Spec-PVDF-PPSU` |
| `SILICA_100C` | `SILICA` |

## Safety logic

The host forces heater off when one of these conditions becomes true:

- door open
- `Hotspot >= hotspotMaxC`
- `Chamber >= chamberMaxC`
- `Chamber >= target + targetOvershootCapC`

For filament, the controller also adds:

- hotspot force-off
- hotspot reheat block
- predictive shutoff before target

## WAIT / door handling

If the door is opened during `RUNNING`:

- host goes into `WAIT`
- heater off
- after manual continue, the run does not resume as a cold start
- instead it uses:
  - resume soak
  - short or medium resume pulse
  - target temperature and interruption duration are both considered

## Fan behavior

For filament:

- after a heating pulse, `FAN230V` is preferred for a fixed amount of time
- switching between `FAN230V` and `FAN230V_SLOW` has a minimum switch delay
- goal: better air mixing without fast toggling

For silica:

- there is currently no dedicated advanced fan hysteresis like filament has
- focus is first on stable bounded pulses

## Parameter matrix

| Parameter | Info | `LOW_45C` | `MID_60C` | `HIGH_80C` | `SILICA_100C` |
|---|---|---:|---:|---:|---:|
| `materialClass` | Coarse material group for existing host-side special logic. | `FILAMENT` | `FILAMENT` | `FILAMENT` | `SILICA` |
| `hysteresisC` | Hysteresis in the `HOLD` area of the base policy. Defines how far chamber may fall below target before reheating is allowed. | `1.5 C` | `1.5 C` | `1.5 C` | `2.5 C` |
| `approachBandC` | Distance to target where the host switches from `BULK_HEAT` to `APPROACH`. | `10.0 C` | `10.0 C` | `10.0 C` | `10.0 C` |
| `holdBandC` | Distance to target where the host enters `HOLD`. | `4.0 C` | `4.0 C` | `4.0 C` | `2.5 C` |
| `targetOvershootCapC` | Hard host safety margin relative to target. If exceeded, the host sets `safetyCutoffActive`. | `+2.0 C` | `+2.0 C` | `+2.0 C` | `+3.0 C` |
| `chamberMaxC` | Absolute maximum chamber temperature for host safety. | `120.0 C` | `120.0 C` | `120.0 C` | `120.0 C` |
| `hotspotMaxC` | Absolute maximum hotspot temperature for host safety. | `140.0 C` | `140.0 C` | `140.0 C` | `140.0 C` |
| `firstPulseMaxMs` | Maximum duration of the very first heating pulse after start. Limits initial energy input. | `10000 ms` | `11000 ms` | `12000 ms` | `45000 ms` |
| `bulkPulseMaxMs` | Maximum duration of a heating pulse in the coarse warm-up area far below target. | `10000 ms` | `10000 ms` | `10000 ms` | `18000 ms` |
| `approachPulseMaxMs` | Maximum duration of a heating pulse in the approach phase near target. | `7000 ms` | `7000 ms` | `7000 ms` | `12000 ms` |
| `holdPulseMaxMs` | Maximum duration of a short reheat pulse in the late hold area. | `6000 ms` | `6000 ms` | `6000 ms` | `8000 ms` |
| `firstSoakMs` | Forces an observation / cooldown phase after the first pulse. Important to avoid run-on overshoot. | `45000 ms` | `45000 ms` | `45000 ms` | `60000 ms` |
| `reheatSoakMs` | Forces a pause between later pulses so the thermal system can settle and be evaluated. | `30000 ms` | `30000 ms` | `30000 ms` | `35000 ms` |
| `safetySoakMs` | Extra lockout time after a safety event before heating is allowed again. | `90000 ms` | `90000 ms` | `90000 ms` | `120000 ms` |
| `bulkPulseEnableBelowTargetC` | Error to target where a full bulk pulse is still allowed instead of a smaller pulse. | `20.0 C` | `20.0 C` | `20.0 C` | `25.0 C` |
| `approachPulseEnableBelowTargetC` | Error to target where an approach pulse is still allowed instead of a hold pulse. | `10.0 C` | `10.0 C` | `10.0 C` | `12.0 C` |
| `reheatEnableBelowTargetC` | Chamber must be at least this far below target before reheating is allowed. | `3.0 C` | `3.0 C` | `2.0 C` | `4.0 C` |
| `forceOffBeforeTargetC` | Direct shutoff reserve before target for later pulses. Avoids too much thermal run-on after late shutoff. | `1.0 C` | `1.0 C` | `1.0 C` | `1.0 C` |
| `firstPulseForceOffBeforeTargetC` | Stronger shutoff reserve for the very first pulse, to soften the first peak. | `2.0 C` | `2.0 C` | `2.0 C` | `2.0 C` |
| `hotspotReheatBlockAboveTargetC` | Blocks a new filament heating pulse if hotspot is still too far above target. | `+5.0 C` | `+5.0 C` | `+5.0 C` | `n/a` |
| `hotspotForceOffAboveTargetC` | Forces heater off for filament if hotspot is far above target. | `+10.0 C` | `+10.0 C` | `+10.0 C` | `n/a` |
| `fanMinSwitchMs` | Minimum switch delay between `FAN230V` and `FAN230V_SLOW` to protect motor and electronics. | `5000 ms` | `5000 ms` | `5000 ms` | `n/a` |
| `fanFastAfterHeatMs` | Keeps fast fan active for a fixed time after a filament heat pulse. | `12000 ms` | `12000 ms` | `12000 ms` | `n/a` |
| `waitResumeSoakMs` | Default lockout time after `WAIT -> RUNNING` before reheating may start again. | `12000 ms` | `12000 ms` | `12000 ms` | `n/a` |
| `waitResumeSoakMinMs` | Lower boundary for resume soak time after `WAIT`. | `5000 ms` | `5000 ms` | `5000 ms` | `n/a` |
| `waitResumeSoakHotTargetMs` | Shorter resume soak for hotter filament targets. | `7000 ms` | `7000 ms` | `7000 ms` | `n/a` |
| `waitResumePulseShortMs` | Short recovery pulse after `WAIT` if only a small temperature gap remains. | `6000 ms` | `6000 ms` | `6000 ms` | `n/a` |
| `waitResumePulseLongMs` | Longer recovery pulse after `WAIT` if the temperature gap is larger. | `8000 ms` | `8000 ms` | `8000 ms` | `n/a` |
| `waitResumeLongPulseErrorC` | Temperature error threshold where the long recovery pulse is used after `WAIT`. | `8.0 C` | `8.0 C` | `8.0 C` | `n/a` |
| `waitResumeMediumPulseErrorC` | Temperature error threshold where a medium recovery pulse is used. | `5.0 C` | `5.0 C` | `5.0 C` | `n/a` |
| `midTargetC` | Threshold where filament targets are treated as medium / higher temperature operation. | `70.0 C` | `70.0 C` | `70.0 C` | `n/a` |
| `waitResumeHotTargetC` | Threshold where filament targets are treated as hot and resumed more conservatively. | `80.0 C` | `80.0 C` | `80.0 C` | `n/a` |
| `waitResumeLongOpenMs` | Door-open duration where the resume path is treated as a longer interruption. | `15000 ms` | `15000 ms` | `15000 ms` | `n/a` |
| `controlStrategy` | Describes the currently used host-side control idea. | `bounded filament pulses + fan hysteresis` | `bounded filament pulses + fan hysteresis` | `bounded filament pulses + fan hysteresis` | `bounded silica pulses, chamber-dominated` |
| `safetyPrimarySensor` | Leading value for safety decisions. | `Chamber + Hotspot` | `Chamber + Hotspot` | `Chamber + Hotspot` | `Chamber primary, Hotspot as extra cutoff` |
| `reheatDecisionBasis` | Main value used to allow new heating pulses. | `Chamber + Hotspot guards` | `Chamber + Hotspot guards` | `Chamber + Hotspot guards` | `Chamber` |

## What already works well

- clear preset-to-profile mapping
- bounded pulses instead of open continuous heating
- good separation between filament and `SILICA_100C`
- dedicated resume path after `WAIT`
- logging with `CSV_HOST_PLOT`, `CSV_HOST_LOGIC`, `CSV_CLIENT_PLOT`, `CSV_CLIENT_LOGIC`

## Where there is still room for improvement

- `LOW_45C` can still become a bit cleaner around the first peak
- `LOW_45C`, `MID_60C` and `HIGH_80C` are separated logically, but not fully fine-tuned yet
- hotspot NTC is still only partially trustworthy in the high-temperature range
- NTC curves may still be improved empirically later

## Short conclusion

The HeaterCurve system is no longer a simple thermostat. It is now a profile-driven pulse controller with safety, soak and resume logic.

The most important point:

- The preset does not only define the target temperature.
- The preset also defines how the oven should thermally get there.

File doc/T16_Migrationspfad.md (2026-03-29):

# T16 Migrationspfad

## Ziel

Dieser Migrationspfad beschreibt den Weg vom aktuell historisch gewachsenen Softwarestand hin zu einer belastbaren, nutzbaren Produkt-Firmware fuer den FilamentSilicaDryer.

Er dient als gemeinsame Arbeitsgrundlage fuer kommende Iterationen.

---

## Ausgangslage

Aktueller Branch:
- `feature/T16_Host_Client_HeaterCurve`

Aktuelle Architektur:
- Host: ESP32-S3, UI, Runtime-State, Heizentscheidung
- Client: ESP32-WROOM, Sensorik, Aktoren, Safety-Gates, Status-Telemetrie
- Kommunikation: UART-basiertes ASCII-Protokoll zwischen Host und Client

Fachliche Kernziele:
- Filament sicher trocknen ohne kritisches Overshoot
- Silicagel mit hoeheren Temperaturen separat behandeln
- Chamber-Temperatur als fuehrende Regelgroesse
- Hotspot-Temperatur nur fuer Safety
- Relais-schonende ON/OFF-Steuerung ohne klassisches Leistungs-PWM

---

## Ist-Befund

Der aktuelle Stand ist keine Nullbasis mehr, sondern eine fortgeschrittene Zwischenstufe.

Bereits vorhanden:
- Dual-NTC-Sensorik im Client
- Protokoll mit Hotspot- und Chamber-Temperatur
- Host als Single Source of Truth fuer Runtime und Heizentscheidung
- Grundsaetzliche Safety-Mechanismen fuer Door, Comm-Loss und Temperaturgrenzen
- Funktionierende Hardware-Ansteuerung fuer Heater, Fans, Lamp und Motor

Noch problematisch:
- Altlogik aus T11/T15 ist im produktiven Code noch sichtbar
- Host-Regelpfad ist semantisch noch nicht komplett auf T16 bereinigt
- Heizlogik ist fachlich noch nicht sauber auf Filament- und Silica-Betrieb getrennt
- Teile der Dokumentation sind veraltet
- Build-Validierung ist aktuell noch nicht sauber in den Analyseablauf integriert

---

## Migrationsprinzipien

Diese Regeln gelten fuer alle naechsten Schritte:

1. Chamber ist die einzige Regelgroesse.
2. Hotspot dient ausschliesslich der Safety-Ueberwachung.
3. Heizlogik liegt ausschliesslich im Host.
4. Der Client bleibt fuer Sensorik, Safety-Gating und Aktor-Ausfuehrung zustaendig.
5. Keine Rueckkehr zu geschaetzten Chamber-Werten.
6. Keine vermischte Alt-/Neu-Architektur im produktiven Pfad.
7. Safety hat immer Vorrang vor UX oder Laufzeit.
8. Undershoot ist akzeptabler als Overshoot.
9. Relais-Schonung ist fester Bestandteil des Reglerdesigns.

---

## Zielbild

### Host
- klare, lesbare Heizlogik ohne T11-Altmodell
- materialabhaengige Regelparameter
- sauberer Runtime-State fuer UI und Diagnose
- explizite Safety-Zustaende und nachvollziehbare Entscheidungen

### Client
- stabile Erfassung beider NTCs
- robuste Status-Telemetrie
- rein technische Ausfuehrung von Host-Kommandos
- zusaetzliche lokale Notfall-Safety als letzte Instanz

### Systemverhalten
- keine unkontrollierten Overshoots bei Filament-Presets
- reproduzierbares Heizverhalten
- saubere Abkuehl- und WAIT/POST-Uebergaenge
- nachvollziehbares Logging fuer Testfahrten

---

## Phasenplan

## Phase 1: Produktiven Regelpfad bereinigen

### Ziel
Den Host-Code auf einen klaren T16-Stand bringen, ohne tote oder irrefuehrende Altlogik.

### Aufgaben
- T11/PT1-Reste im produktiven Host-Pfad identifizieren
- nicht mehr genutzte Legacy-Felder, Legacy-Kommentare und Altannahmen entfernen oder isolieren
- Runtime-State semantisch auf Chamber/Hotspot ausrichten
- Kommentare und Benennungen an die reale T16-Architektur anpassen

### Ergebnis
- `oven.cpp` und `oven.h` beschreiben nur noch die produktive Dual-NTC-Logik
- geringeres Risiko fuer Fehlentscheidungen bei Weiterentwicklung

---

## Phase 2: Heizentscheidung fachlich fixieren

### Ziel
Ein belastbares Host-Regelverhalten definieren, das Overshoot vermeidet und das Relais schont.

### Aufgaben
- Startverhalten des Heaters sauber definieren
- Hysterese und Safety-Schwellen zentral modellieren
- Mindest-EIN/AUS-Zeiten verbindlich integrieren
- Unterschied zwischen `heater_request_on` und `heater_actual_on` konsequent durchziehen
- unnoetige wiederholte `SET`-Frames vermeiden

### Ergebnis
- technisch stabile und nachvollziehbare Heizentscheidung
- reduzierte Kommunikationslast
- bessere Basis fuer reale Heiztests

---

## Phase 3: Temperatur-Policy pro Betriebsart

### Ziel
Filament-Trocknung und Silica-Trocknung fachlich sauber trennen.

### Aufgaben
- Presets fachlich kategorisieren
- Regeln fuer Filament-Betrieb definieren:
  - max. tolerierte Ueberschreitung
  - erlaubte Dauer einer Ueberschreitung
  - konservative Wiedereinschaltstrategie
- Regeln fuer Silica-Betrieb definieren:
  - hoeherer Zielbereich
  - tolerantere Ueberschreitung
  - eigene Safety- und Komfortparameter
- gemeinsame absolute Sicherheitsgrenzen beibehalten

### Ergebnis
- Presets bilden reale Materialanforderungen ab
- Filament wird konservativ geschuetzt
- Silica kann effektiver getrocknet werden

---

## Phase 4: Telemetrie, Logging und Diagnose schaerfen

### Ziel
Das Verhalten des Systems bei Testfahrten objektiv auswertbar machen.

### Aufgaben
- wichtige Reglerentscheidungen strukturiert loggen
- Temperaturverlauf Chamber vs. Hotspot sauber nachvollziehbar machen
- Safety-Ereignisse und Schaltvorgaenge eindeutig kennzeichnen
- Logging auf die T16-Zielarchitektur reduzieren

### Ergebnis
- echte Testdaten statt Bauchgefuehl
- bessere Grundlage fuer Regler-Tuning

---

## Phase 5: Reale Heizkurven validieren und tunen

### Ziel
Die Heizstrategie auf echter Hardware iterativ verbessern.

### Aufgaben
- definierte Testprozeduren je Preset oder Materialklasse aufstellen
- Aufheizverhalten, Overshoot und Ausschwingverhalten messen
- Parameter iterativ anpassen
- Abbruchkriterien fuer unsichere Testlaeufe festlegen

### Ergebnis
- belastbare Heizkurven statt theoretischer Annahmen
- reproduzierbares Verhalten fuer reale Nutzung

---

## Phase 6: Dokumentation auf Produktionsstand bringen

### Ziel
Nur noch Dokumentation pflegen, die dem realen Codezustand entspricht.

### Aufgaben
- veraltete Dokumente markieren oder archivieren
- Architektur, Zustandsmodell und Safety-Regeln neu dokumentieren
- Test- und Inbetriebnahmehinweise aktualisieren
- dieses Dokument nach jeder relevanten Iteration fortschreiben

### Ergebnis
- weniger Missverstaendnisse
- schnellerer Wiedereinstieg in spaeteren Sessions

---

## Konkrete Reihenfolge fuer die naechsten Iterationen

1. Host-Regelpfad bereinigen
2. offensichtliche Safety- und Zustandsfehler beheben
3. Heizentscheidung und Schwellwerte zentralisieren
4. redundante Kommandos und Legacy-Artefakte entfernen
5. Logging fuer Heiztests schaerfen
6. erste reale Testfahrt gegen PLA oder TPU vorbereiten
7. danach Materialklassen und Preset-Policy verfeinern

---

## Bekannte Risiken

- Historische Altlogik kann unbemerkt weiterwirken
- reale thermische Traegheit kann theoretische Schwellen unbrauchbar machen
- Sensorplatzierung kann trotz Dual-NTC weiterhin lokale Artefakte erzeugen
- Kommunikations-Sonderfaelle koennen Host- und Client-Zustand auseinanderziehen
- Build- oder Flash-Prozess kann Analyse und schnelle Iteration ausbremsen

---

## Definition of Done fuer T16

T16 ist fuer den produktiven Einsatz ausreichend abgeschlossen, wenn:

- Chamber-only-Regelung produktiv und eindeutig umgesetzt ist
- Hotspot-only-Safety stabil greift
- Relais-Schonung nachweisbar eingehalten wird
- Filament-Presets ohne kritisches Overshoot fahrbar sind
- Silica-Betrieb separat und sicher funktioniert
- Runtime-State, UI und Telemetrie konsistent sind
- Altlogik aus T11/T15 den produktiven Pfad nicht mehr verunklaert

---

## Arbeitsmodus fuer kommende Sessions

Bei jeder neuen Iteration:

1. zuerst dieses Dokument gegen den Codezustand abgleichen
2. den aktuellen Arbeitsschritt einer Phase zuordnen
3. nach Abschluss den Fortschritt hier nachziehen
4. neue Risiken oder Erkenntnisse hier ergaenzen

So bleibt der Migrationspfad dauerhaft die gemeinsame Referenz zwischen Analyse, Umsetzung und Test.

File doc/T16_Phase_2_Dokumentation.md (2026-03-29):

# T16 Phase 2 Dokumentation

## Ziel

Phase 2 hebt die Host-Heizkurve von einer einfachen Einheits-Hysterese auf eine fachlich getrennte und besser beobachtbare Regelbasis:

- getrennte Host-Policy fuer `Filament` und `Silica`
- einfache mehrstufige Heizstrategie
- erweiterte Host-Logs fuer spaetere Hardware-Analyse

## Umgesetzte Schritte

### T16_Phase_2.1

- `HeaterMaterialClass` eingefuehrt:
  - `FILAMENT`
  - `SILICA`
- `HeaterPolicy` eingefuehrt
- Presets tragen jetzt explizit ihre Materialklasse
- Host waehlt seine Heizparameter anhand der aktiven Materialklasse

### T16_Phase_2.2

- `HeaterControlStage` eingefuehrt:
  - `IDLE`
  - `BULK_HEAT`
  - `APPROACH`
  - `HOLD`
- dreistufige Heizentscheidung im Host-Regelpfad implementiert
- `tempToleranceC` bildet jetzt den jeweils aktiven Regelbereich der aktuellen Heizphase ab

### T16_Phase_2.3 / T16_Phase_2.3.1

- Host-Logic-CSV um `materialClass` und `heaterStage` erweitert
- CSV-Schema und Runtime-Ausgabe wieder konsistent gemacht

## Architekturstand

```mermaid
flowchart LR
    A["Client: ADS1115 + Door"] --> B["Protocol STATUS"]
    B --> C["Host RuntimeState"]
    C --> D["Material Policy"]
    D --> E["Stage Decision"]
    E --> F["Relay Guard 2s/2s"]
    F --> G["SET outputsMask"]
    C --> H["CSV_HOST_TEMP / CSV_HOST_LOGIC"]
```

## Aktuelle Heizlogik

### Materialklassen

- `Filament`
  - engere Heizstrategie
  - kleinere tolerierte Zielueberschreitung
- `Silica`
  - groesseres Hysterese-/Annäherungsfenster
  - groessere tolerierte Zielueberschreitung innerhalb der Host-Policy

### Heizphasen

- `BULK_HEAT`
  - System ist noch klar unter Soll
  - Heizer wird grundsaetzlich angefordert, solange keine Safety aktiv ist
- `APPROACH`
  - System naehrt sich dem Soll
  - Regelung wird frueher defensiv
- `HOLD`
  - Zielbereich erreicht
  - undershoot-lastige Nachregelung, um Overshoot zu vermeiden

## Wichtige Grenzen

- Door open => Heater aus
- Chamber max => Heater aus
- Hotspot max => Heater aus
- Target + Overshoot-Cap => Heater aus
- Relais-Schutz:
  - min ON = 2s
  - min OFF = 2s

## Betroffene Dateien

- `include/oven.h`
- `src/app/oven/oven.cpp`
- `include/log_csv.h`

## Bewertung

Phase 2 liefert jetzt keine optimierte End-Heizkurve, aber eine brauchbare fachliche Basis:

- Chamber regelt, Hotspot schuetzt
- Materialklassen sind getrennt modelliert
- Heizphasen sind sichtbar modelliert
- Logging ist fuer reale Heizlaeufe nutzbar

Was noch nicht fertig ist:

- Feintuning der Schwellen anhand echter Messlaeufe
- materialfeiner Ausbau innerhalb `Filament`
- abgesicherte Aussagen zur realen Overshoot-Guete

## Build-Status

Zum Abschluss der Phase erfolgreich gebaut:

- `pio run -e host_esp32s3_st7701`
- `pio run -e client_esp32_wroom`

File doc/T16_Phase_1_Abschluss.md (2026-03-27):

# T16 Phase 1 Abschluss

Phase 1 wurde erfolgreich abgeschlossen.

Referenzdokument:
- [`doc/T16_Phase_1_Dokumentation.md`](/Users/bernhardklein/workspace/arduino/esp32/FilamentSilicatDryer_480x480/doc/T16_Phase_1_Dokumentation.md)

Enthaltene Unterschritte:
- `T16_Phase_1.0`
- `T16_Phase_1.1`
- `T16_Phase_1.2`
- `T16_Phase_1.3`
- `T16_Phase_1.4`

Ergebnis:
- produktiver Host-Regelpfad ist deutlich bereinigt
- Safety-Entscheidung ist zentralisiert
- blindes Heater-ON beim Start ist entfernt
- redundanter Heater-SET-Traffic ist reduziert
- Host-Regelschwellen sind zentralisiert
- Software-Version ist auf `0.5.0` angehoben

Naechste Phase:
- Phase 2 fokussiert auf fachliche Heizstrategie und materialabhaengige Regeln

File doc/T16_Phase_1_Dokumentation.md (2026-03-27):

# T16 Phase 1 Dokumentation

## Status

Phase 1 ist abgeschlossen.

Ziel von Phase 1 war die Bereinigung des produktiven Host-Regelpfads, damit die Dual-NTC-Architektur im Code klarer sichtbar wird und historische T11-Reste den weiteren Ausbau nicht mehr verunklaeren.

Diese Phase war ein reiner Struktur- und Konsolidierungsschritt.
Ein sinnvoller Hardware-Runtimetest war dafuer noch nicht zwingend erforderlich.

---

## Scope von Phase 1

Bearbeitet wurde ausschliesslich der produktive Host-Regelpfad plus die technische Versionsangabe.

Schwerpunkte:
- historische T11-Reste aus dem produktiven Pfad entfernen
- Safety-Semantik im Host klarer machen
- Startverhalten des Heaters sicherer machen
- redundanten Kommunikations-Traffic reduzieren
- Regelschwellen zentralisieren
- Versionierung auf `<major>.<minor>.<patch>` vorbereiten

Nicht Ziel dieser Phase:
- materialabhaengige Heizkurven
- neue Presetlogik
- reale Hardware-Heiztests
- Tuning auf PLA, TPU, PETG oder Silica

---

## Umgesetzte Schritte

## T16_Phase_1.0

Commit:
- `926c758`

Inhalt:
- produktive T11-Reste in [`oven.cpp`](/Users/bernhardklein/workspace/arduino/esp32/FilamentSilicatDryer_480x480/src/app/oven/oven.cpp) und [`oven.h`](/Users/bernhardklein/workspace/arduino/esp32/FilamentSilicatDryer_480x480/include/oven.h) entfernt
- veraltete Thermal-Model-Strukturen und irrefuehrende Legacy-Kommentare aus dem aktiven Host-Pfad entfernt
- `safetyCutoffActive` korrigiert, so dass der Door-Fall im Safety-Status enthalten ist

Wirkung:
- der produktive Code beschreibt jetzt deutlicher Chamber als Control und Hotspot als Safety

---

## T16_Phase_1.1

Commit:
- `9a89a23`

Inhalt:
- Host sendet Heater-`SET`-Frames im RUNNING-Pfad nur noch bei echter Maskenaenderung

Wirkung:
- weniger UART-/ACK-Traffic
- bessere Lesbarkeit von Logs
- weniger unnoetige Last auf dem Host-Client-Kommunikationspfad

---

## T16_Phase_1.2

Commit:
- `8809b40`

Inhalt:
- [`oven_start()`](/Users/bernhardklein/workspace/arduino/esp32/FilamentSilicatDryer_480x480/src/app/oven/oven.cpp) startet nicht mehr mit blindem `HEATER=ON`
- Heater-Intent und Heater-Effective werden beim Start explizit auf `false` gesetzt

Wirkung:
- kein ungepruefter Heizimpuls direkt beim Start
- erste Heizanforderung kommt sauber aus dem normalen Regelpfad

---

## T16_Phase_1.3

Commit:
- `87e072d`

Inhalt:
- zentrale Host-Konstanten fuer Hysterese, Overshoot-Cap und absolute Safety-Grenzen eingefuehrt
- Default-Hysterese des Runtime-State an diese zentralen Konstanten gebunden

Wirkung:
- weniger verstreute Schwellwerte
- bessere Grundlage fuer spaetere Material- und Profilpolitik

---

## T16_Phase_1.4

Commit:
- `ac496f7`

Inhalt:
- Host-Safety-Entscheidung in eine eigene Helper-Funktion gekapselt
- Versionsangaben in [`versions.h`](/Users/bernhardklein/workspace/arduino/esp32/FilamentSilicatDryer_480x480/include/versions.h) auf `0.5.0` und auf das SemVer-Schema umgestellt
- String-Literale dort gleichzeitig technisch sauber als `const char[]` modelliert

Wirkung:
- Safety-Regeln sind zentral gebuendelt
- naechste fachliche Schritte koennen gezielter auf einer Stelle aufsetzen
- Versionierung ist weniger historisch und besser wartbar

---

## Architekturstand nach Phase 1

### Rollenmodell

- Host:
  - UI
  - Runtime-State
  - Heizentscheidung
  - Hysterese und Safety-Policy
- Client:
  - Sensorik
  - Aktor-Ansteuerung
  - lokale Safety-Gates
  - Status-Telemetrie

### Temperaturmodell

- `tempChamberC`:
  - fuehrende Regelgroesse
  - UI-relevante Temperatur
- `tempHotspotC`:
  - Safety-Temperatur
  - keine direkte Regelgroesse

### Heater-Modell

- `heater_request_on`:
  - Host-Entscheidung
- `heater_actual_on`:
  - effektiver, relais-konformer Heizstatus

---

## Mermaid Uebersicht

```mermaid
flowchart TD
    A["Client liest NTCs und IO-Zustand"] --> B["STATUS an Host"]
    B --> C["Host aktualisiert OvenRuntimeState"]
    C --> D["Safety-Pruefung<br/>Door / Chamber max / Hotspot max / Overshoot cap"]
    D --> E["Heater-Entscheidung<br/>Hysterese um tempTarget"]
    E --> F["Relais-Schutz<br/>Min ON/OFF"]
    F --> G["SET nur bei Maskenaenderung"]
    G --> H["Client setzt Ausgaenge um"]
    H --> A
```

---

## Betroffene Dateien in Phase 1

- [`include/oven.h`](/Users/bernhardklein/workspace/arduino/esp32/FilamentSilicatDryer_480x480/include/oven.h)
- [`include/versions.h`](/Users/bernhardklein/workspace/arduino/esp32/FilamentSilicatDryer_480x480/include/versions.h)
- [`src/app/oven/oven.cpp`](/Users/bernhardklein/workspace/arduino/esp32/FilamentSilicatDryer_480x480/src/app/oven/oven.cpp)

---

## Compile-Status

Alle Unterschritte dieser Phase wurden jeweils erfolgreich gebaut mit:

- `pio run -e host_esp32s3_st7701`
- `pio run -e client_esp32_wroom`

Damit ist Phase 1 durchgehend compilefaehig abgeschlossen worden.

---

## Bekannte Restpunkte nach Phase 1

- die fachliche Heizstrategie ist noch generisch und noch nicht materialklassen-spezifisch
- Presets transportieren noch keine differenzierte Regelpolitik fuer Filament vs. Silica
- reale thermische Validierung auf Hardware steht noch aus
- veraltete Dokumente im Repo existieren weiterhin und muessen spaeter bereinigt werden

---

## Empfehlung fuer Phase 2

Phase 2 sollte jetzt auf die fachliche Heizentscheidung gehen:

1. Safety- und Regelpfad fachlich fuer Filament und Silica differenzieren
2. Overshoot-Regeln materialabhaengig modellieren
3. Wieder-Einschaltstrategie und konservatives Verhalten bei Filamenten schaerfen
4. danach gezielt Hardware-Runtimetests vorbereiten

Spätestens ab Phase 2 oder kurz danach sind echte Hardware-Runtimetests sinnvoll und fachlich wichtig.

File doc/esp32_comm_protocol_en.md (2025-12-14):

# ESP32-S3 ↔ ESP32-WROOM Communication Protocol (Step 2 Documentation)

## Summary of Requirements

This document outlines the communication protocol between a HOST (ESP32-S3) and a CLIENT (ESP32-WROOM).  
The HOST provides a touchscreen user interface, while the CLIENT controls up to 16 I/O channels and reads various sensor inputs.  
Communication occurs via UART using a structured ASCII-based protocol.

### System Requirements

- **16 communication channels total**
  - **12 digital IN/OUT** channels (CH0–CH11)
  - **4 hybrid channels** (CH12–CH15) supporting:
    - Digital IN/OUT
    - Analog input (ADC raw values)
- **Temperature measurement** from a MAX6675 thermocouple module connected to the CLIENT.
- **UART-based ASCII protocol**, easy to debug and parse.
- **Hex-based 16‑bit digital mask** for all channel states.
- **Four ADC channels** transmitted as raw integer values (0–4095).
- **Temperature** transmitted as an integer in 0.25°C resolution: `temp_raw = °C × 4`.

---

# Step 2 – Communication Protocol Specification

## 1. Channel Definition

### 1.1 Channel Overview

| Channel | Bit | Mask | Type | Notes |
|---|-----|---|---|---|
| CH0 | 0 | 0x0001 | Digital IN/OUT | Example: Heater |
| CH1 | 1 | 0x0002 | Digital IN/OUT | Example: Fan230V |
| CH2 | 2 | 0x0004 | Digital IN/OUT | Example: Fan230V-Slow |
| CH3 | 3 | 0x0008 | Digital IN/OUT | Example: Fan12V |
| CH4 | 4 | 0x0010 | Digital IN/OUT | Example: Lamp |
| CH5 | 5 | 0x0020 | Digital IN/OUT | Example: Motor |
| CH6 | 6 | 0x0040 | Digital IN/OUT | Free |
| CH7 | 7 | 0x0080 | Digital IN/OUT | Free |
| CH8 | 8 | 0x0100 | Digital IN/OUT | Free |
| CH9 | 9 | 0x0200 | Digital IN/OUT | Free |
| CH10 | 10  | 0x0400 | Digital IN/OUT | Free |
| CH11 | 11  | 0x0800 | Digital IN/OUT | Free |
| CH12 | 12  | 0x1000 | Digital + Analog 0 | ADC channel A0 |
| CH13 | 13  | 0x2000 | Digital + Analog 1 | ADC channel A1 |
| CH14 | 14  | 0x4000 | Digital + Analog 2 | ADC channel A2 |
| CH15 | 15  | 0x8000 | Digital + Analog 3 | ADC channel A3 |

### 1.2 Digital Mask

A full 16‑bit digital mask represents the ON/OFF state of all channels.

- Format: **4‑digit HEX**, always padded, e.g.:
  - `0000` → all LOW  
  - `0001` → CH0 HIGH  
  - `1009` → CH0 + CH3 + CH12 HIGH

---

## 2. Analog Inputs

The CLIENT provides **four ADC values** mapped to channels:

| ADC Input | Channel | Field Name |
|---|---|---|
| ADC0 | CH12 | adc0_raw |
| ADC1 | CH13 | adc1_raw |
| ADC2 | CH14 | adc2_raw |
| ADC3 | CH15 | adc3_raw |

Values are raw integers **0–4095**.  
Voltage calculation and scaling are performed on the HOST.

---

## 3. Temperature Input (MAX6675)

- Temperature is transmitted as `temp_raw = °C × 4`
  - 25.00°C → `100`
  - 123.75°C → `495`

This preserves 0.25°C resolution.

---

## 4. UART Protocol Structure

Messages follow this structure:

```
<Sender>;<Command>[;Argument1;Argument2;...]\r\n
```

- **Sender:**  
  - `H` = HOST  
  - `C` = CLIENT  
- **Field separator:** `;`  
- **Line ending:** `
`

---

# 5. Commands

## 5.1 HOST → CLIENT Commands

### 5.1.1 SET – Write Digital Mask

Sets all 16 digital outputs.

```
H;SET;<bitmask16_hex>

```

Example:  
Enable CH0, CH3, CH4:

```
H;SET;0019

```

---

### 5.1.2 GET STATUS – Request Status Update

```
H;GET;STATUS

```

---

### 5.1.3 PING

```
H;PING

```

---

## 5.2 CLIENT → HOST Responses

### 5.2.1 ACK / ERR for SET

Success:

```
C;ACK;SET;<bitmask16_hex>

```

Error:

```
C;ERR;SET;<error_code>

```

---

### 5.2.2 STATUS – Full State Report

**Extended format supporting 16 digital channels + 4 ADCs + temperature:**

```
C;STATUS;<bitmask16_hex>;<adc0_raw>;<adc1_raw>;<adc2_raw>;<adc3_raw>;<temp_raw>

```

Example:

```
C;STATUS;0013;1000;2000;3000;4095;100

```

---

### 5.2.3 PONG

```
C;PONG

```

---

# End of Document

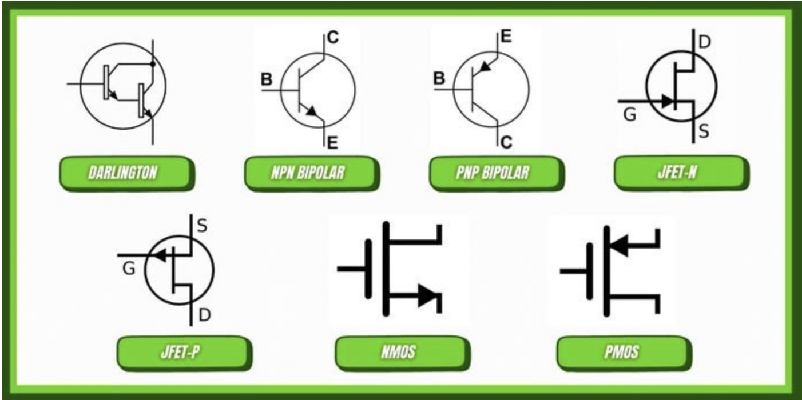
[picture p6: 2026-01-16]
doc/images/transisotor_overview.png

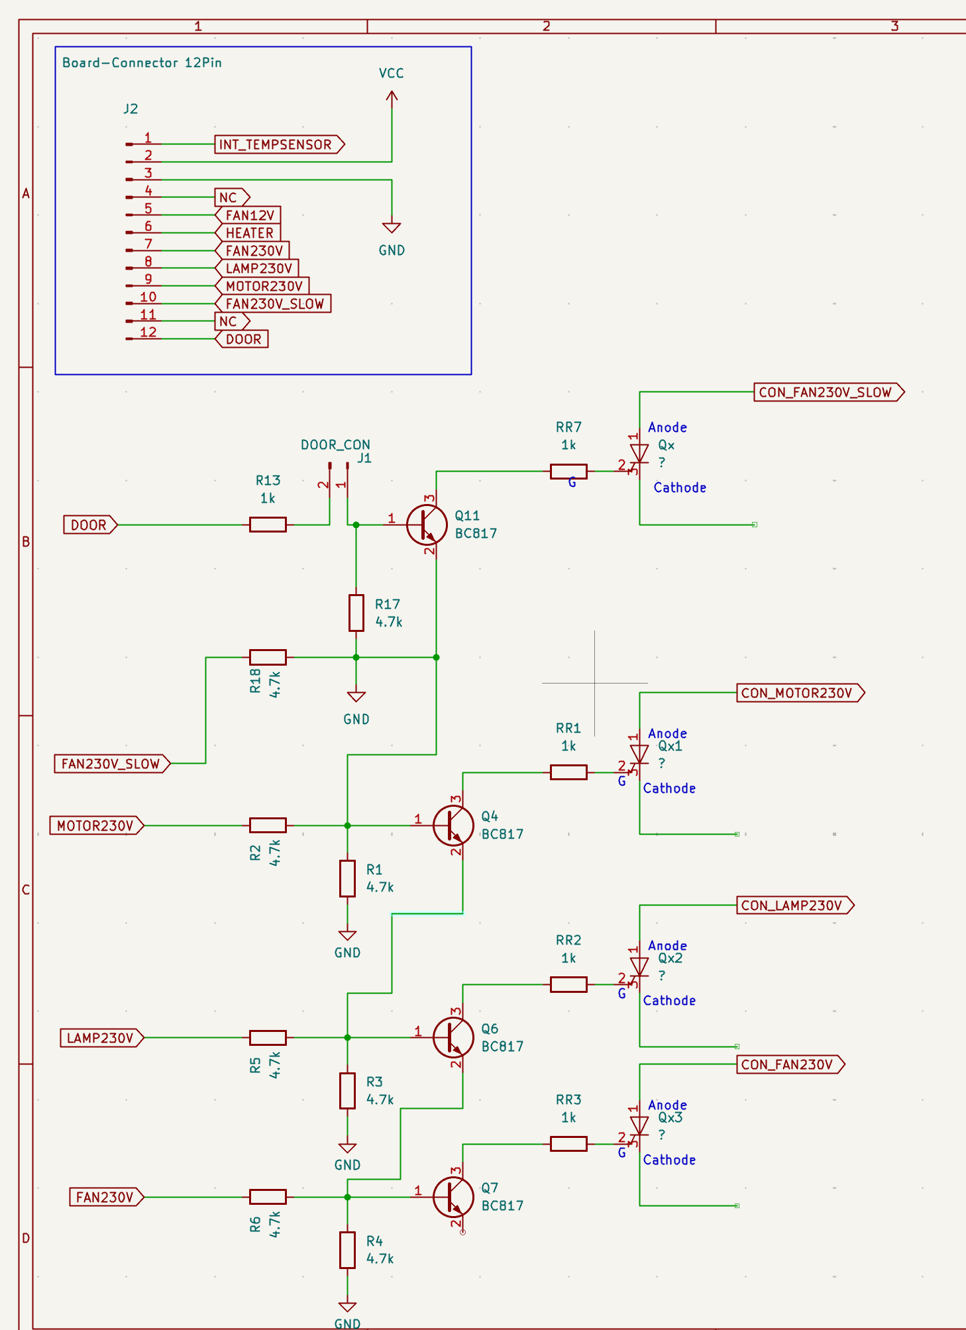
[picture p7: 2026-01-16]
doc/images/Bildschirmfoto 2026-01-16 um 16.53.05.png

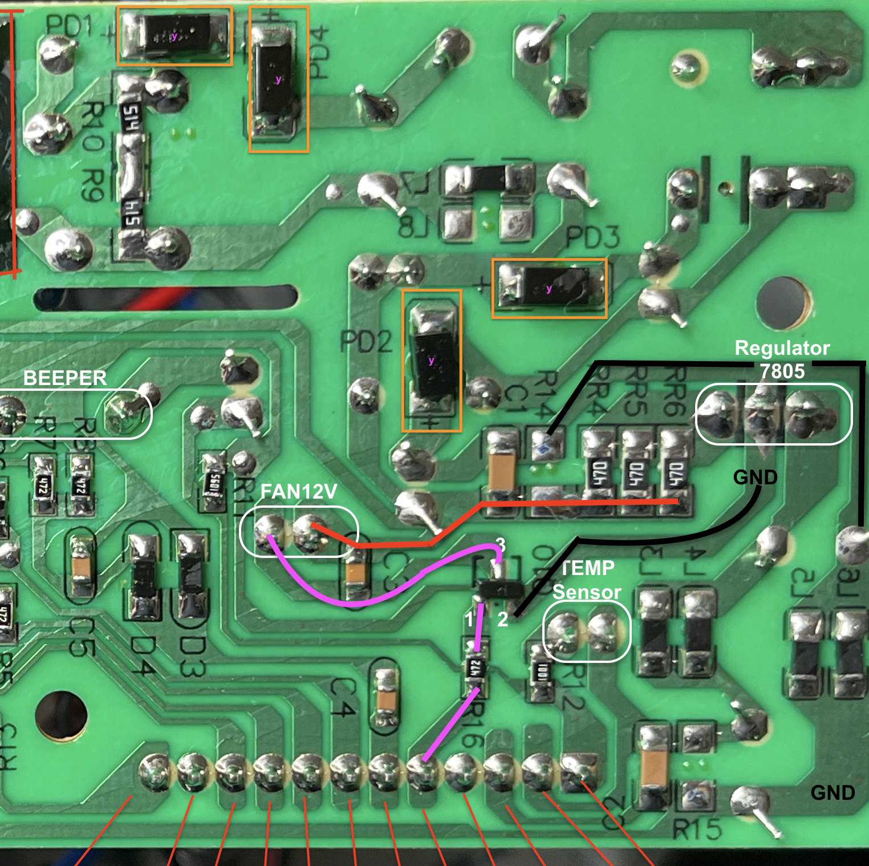
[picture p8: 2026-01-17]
doc/images/PowerBoard_Detail_PD1-PD4.png

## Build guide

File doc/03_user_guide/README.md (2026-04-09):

# User Guide

This section is the operator-facing documentation for the current product behavior.

Contents:

1. [Installation and safety](01_installation_and_safety.md)
2. [Operation and screens](02_operation_and_screens.md)

## Current release focus

Release `0.7.1` adds or consolidates:

- configurable parameter screen
- persistent fast shortcuts
- persistent heater-curve settings
- display timeout with dimming and wake-on-touch protection

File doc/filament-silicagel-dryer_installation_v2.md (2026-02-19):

# Filament & SilicaGel Dryer – Installation

Diese Anleitung beschreibt die Installation für beide Controller:

- **HOST**: ESP32‑S3 (480×480 Touch‑UI, LVGL 9.4.x)
- **CLIENT**: ESP32‑WROOM (Powerboard‑Controller, Hardware‑I/O)

Es gibt zwei Wege:

1) **Non‑Developer**: Fertige Firmware flashen (HOST + CLIENT)  
2) **Developer**: Projekt aus dem Repo bauen, flashen und debuggen

> Grundannahme: Du hast **Basiswissen** zum Flashen von ESP32 (USB‑Port, Treiber, COM‑Port finden).  
> Ziel hier: **so viel wie nötig, so wenig wie möglich**.

---

## 0) Voraussetzungen (für beide Wege)

### Hardware
- ESP32‑S3 Board (HOST) mit 480×480 RGB‑Panel (ST7701)
- ESP32‑WROOM Board (CLIENT)
- USB‑Kabel (datenfähig)
- Optional: USB‑UART Adapter (falls Board keinen nativen USB hat)

### Software
Wähle **eine** der folgenden Optionen:

- **Option A (empfohlen)**: VS Code + PlatformIO
- **Option B**: `esptool.py` (direkt per CLI)

---

## 1) Non‑Developer: Fertige Firmware flashen (HOST + CLIENT zusammen)

> ⚠️⚠️⚠️⚠️⚠️ [!WARNING] ⚠️⚠️⚠️⚠️⚠️
> 
> **!!!!! NIE USB verwenden, wenn Netzstecker eingesteckt ist !!!!!!!**

### 1.1 Dateien (Firmware Artefakte)
Du brauchst **zwei** Images (werden vom Projekt bereitgestellt):

- `host_esp32s3.bin` (oder `.hex`, je nach Release-Format)
- `client_esp32wroom.bin`

> Hinweis: Bei ESP32 sind **.bin** üblich. Falls eure Releases „.hex“ heißen, ist das ok – die Flash-Kommandos unterscheiden sich je nach Tool.  
> In den Beispielen unten wird **.bin** verwendet, weil das mit `esptool.py` Standard ist.

---

### 1.2 Flashen mit VS Code + PlatformIO (einfachster Weg)

> ⚠️⚠️⚠️⚠️⚠️ [!WARNING] ⚠️⚠️⚠️⚠️⚠️
> 
> **!!!!! NIE USB verwenden, wenn Netzstecker eingesteckt ist !!!!!!!**

1. VS Code installieren  
2. Extension **PlatformIO IDE** installieren  
3. Projekt öffnen (oder „PIO Home → Open Project“)  
4. **Board/Environment auswählen** (HOST bzw. CLIENT – je nach Projektstruktur)

Dann:

- Für **HOST**: `Upload` (Pfeil) ausführen  
- Für **CLIENT**: danach Board umstecken und ebenfalls `Upload` ausführen

> Wenn ihr Releases ohne Repo-Build nutzen wollt, ist PlatformIO weniger ideal (weil PIO normalerweise baut). In dem Fall: nutze Option **1.3 esptool.py**.

---

### 1.3 Flashen mit `esptool.py` (CLI, robust, minimal)

> ⚠️⚠️⚠️⚠️⚠️ [!WARNING] ⚠️⚠️⚠️⚠️⚠️
> 
> **!!!!! NIE USB verwenden, wenn Netzstecker eingesteckt ist !!!!!!!**

#### Installation `esptool`
```bash
python3 -m pip install --user esptool
```

#### Port finden
- macOS: typischerweise `/dev/tty.usbmodem*` oder `/dev/tty.usbserial*`
- Linux: `/dev/ttyACM0` oder `/dev/ttyUSB0`
- Windows: `COM3`, `COM5`, …

Beispiele:
```bash
# macOS / Linux
ls /dev/tty.* 2>/dev/null || true
ls /dev/ttyACM* /dev/ttyUSB* 2>/dev/null || true
```

---

#### WICHTIG: Flash-Adresse
Für ESP32-Firmware wird sehr häufig an **0x0** geflasht (monolithisches Image).  
Wenn euer Release **mehrere Binaries** enthält (bootloader/partition/table/app), dann müsst ihr die jeweils **korrekten Offsets** verwenden.

✅ **Best-Practice**: Der Release sollte eine `flash_cmd.txt` oder Release-Notes mit Offsets enthalten.

Im Zweifel (und wenn ihr nur **ein** `.bin` habt): **0x0**.

---

#### HOST flashen (ESP32‑S3)
```bash
esptool.py --chip esp32s3 --port /dev/tty.usbmodemXXXX --baud 921600 erase_flash
esptool.py --chip esp32s3 --port /dev/tty.usbmodemXXXX --baud 921600 write_flash -z 0x0 host_esp32s3.bin
```

#### CLIENT flashen (ESP32‑WROOM)
```bash
esptool.py --chip esp32 --port /dev/ttyUSB0 --baud 921600 erase_flash
esptool.py --chip esp32 --port /dev/ttyUSB0 --baud 921600 write_flash -z 0x0 client_esp32wroom.bin
```

> Wenn der Chip-Typ nicht passt:  
> - WROOM ist meist `esp32` (klassisch)  
> - S3 ist `esp32s3`  
> Falls unsicher: `esptool.py chip_id` testen.

#### Optional: Chip erkennen / Verbindung testen
```bash
esptool.py --port /dev/tty.usbmodemXXXX chip_id
```
---
## 2) Tests / Validierung

### 2.1 Minimaltest ohne CLIENT (HOST allein)
Ohne CLIENT ist das System nur eingeschränkt sinnvoll. Erwartbar ist:

- HOST bootet ohne Crash
- **screen_main** sichtbar
- Swipe zu **screen_config**
- Swipe zu **screen_dbg_hw**
- Keine „echten“ Hardware-Zustände (Telemetrie fehlt)

Das reicht als „Display/Touch/Basic UI“‑Smoke‑Test.

### 2.2 Validierung mit CLIENT (empfohlen)
Wenn HOST↔CLIENT verbunden sind (UART/TTL) und der CLIENT läuft:

- Link/Sync Indicator wird plausibel (je nach Implementierung: „synced“)
- STATUS/ACK‑Traffic sichtbar (falls Logs aktiv)
- `screen_dbg_hw` zeigt reale I/O Zustände und kann (bei aktivem RUN-Gate) toggeln

---

## 3) Developer: Build / Compile / Flash

<div style="border: 2px solid red; padding: 15px; text-align: center; font-size: 30px; color: red; font-weight: bold; border-radius: 5px;">
    !!!!! NIE USB verwenden, wenn Netzstecker eingesteckt ist !!!!!!!
</div>
<br><br>

> Für Entwickler: Ziel ist reproduzierbarer Build via PlatformIO.

### 3.1 Projektsetup (VS Code + PlatformIO)
1. VS Code + PlatformIO installieren  
2. Repo klonen:
```bash
git clone <REPO>
cd <REPO>
```
3. In VS Code öffnen

### 3.2 PlatformIO Environments
Die konkreten Environments stehen in `platformio.ini`.

Typischer Ablauf:
- Environment für **HOST** bauen/flashen
- Environment für **CLIENT** bauen/flashen

Beispiele (CLI):
```bash
# Build
pio run -e host

# Flash
pio run -e host -t upload

# Monitor (optional)
pio device monitor -b 115200
```

Analog für den Client:
```bash
pio run -e client
pio run -e client -t upload
```

> Ersetze `host`/`client` durch eure tatsächlichen Environment-Namen.

---

## 4) Libraries / Abhängigkeiten

Die vollständige Liste ist in `platformio.ini` definiert (Single Source of Truth).

Typisch (HOST):
- LVGL **9.4.x**
- Arduino_GFX_Library (RGB Panel / ST7701 init)
- ggf. Touch-Lib (je nach Panel/Controller)

Typisch (CLIENT):
- UART/Protocol Layer (eigen)
- GPIO/Relais-Treiber (Powerboard)

> Bitte orientiere dich **immer** an `platformio.ini` eures Repos.

---

## 5) Troubleshooting (Kurz)

- **esptool findet Port nicht**: anderes USB-Kabel, Treiber, Port prüfen
- **Schreibfehler / Timeout**: Baudrate reduzieren (z.B. 460800 oder 115200)
- **Boot-Loop**: falsches Board/Chip, falsches Image, falscher Offset
- **Display schwarz**: Backlight-Pin, PCLK, ST7701 Init-Sequenz, RGB/BGR

---

## 6) Safety-Hinweise
- `screen_dbg_hw` ist ein **Testscreeen**.  
  Er darf nur genutzt werden, wenn das System **nicht** im „Running“‑Betrieb ist.
- Bei Navigation/Swipe aus dem Debug-Screen muss ein **Safe‑Off** erzwungen werden (Projekt-Policy).

<div style="border: 2px solid red; padding: 15px; text-align: center; font-size: 30px; color: red; font-weight: bold; border-radius: 5px;">
    !!!!! NIE USB verwenden, wenn Netzstecker eingesteckt ist !!!!!!!
</div>

---

---
# Trouble-Shooting / Compiler / Linker Fehler

## LVGL-Asm (Helium) deaktivieren durch eine Datei löschen

- **Fehler:** 
`.pio/build/host_esp32s3_st7701/libb8e/lvgl/draw/sw/blend/helium/lv_blend_helium.S.o error`
- **Lösung:** 
`rm -f .pio/libdeps/host_esp32s3_st7701/lvgl/src/draw/sw/blend/helium/lv_blend_helium.S`

## Drift Screen
Bildschirm schiebt sich nach rechts aus dem Rand und kommt links wieder rein
```
  // RGB pixel clock. Higher values increase bandwidth and may cause slow horizontal drift/wrap on some panels.
// 12 MHz proved stable in long-running tests.
static constexpr uint32_t RGB_PCLK_HZ = 12'000'000;

```
runter setzen auf 10'000'000 oder was anderes

**END OF FILE**

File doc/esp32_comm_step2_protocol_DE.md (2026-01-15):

# ESP32-S3 ↔ ESP32-WROOM Kommunikationsprotokoll (Schritt 2 Dokumentation)

> **(bitte beachten, ggf. etwas veraltet)**

## Zusammenfassung der Anforderungen

Dieses Dokument beschreibt das Kommunikationsprotokoll zwischen dem **HOST** (ESP32-S3) und dem **CLIENT** (ESP32-WROOM).  
Der HOST stellt eine Touchscreen-Benutzeroberfläche bereit, während der CLIENT bis zu **16 Kanäle** steuert und Sensordaten erfasst.  
Die Kommunikation erfolgt über **UART** mit einem strukturierten **ASCII-Textprotokoll**.

### Systemanforderungen

- **16 Kanäle insgesamt**
  - **12 digitale IN/OUT-Kanäle** (CH0–CH11)
  - **4 hybride Kanäle** (CH12–CH15), die unterstützen:
    - Digital IN/OUT
    - Analogmessung (ADC-Rohwerte)
- **Temperaturmessung** über MAX6675 Thermoelementmodul (am CLIENT angeschlossen).
- **UART-basiertes ASCII-Protokoll**, leicht debugbar.
- **16-Bit-Digitalmaske** (Hex-Darstellung) zur Kanalsteuerung.
- **4 ADC-Werte** (0–4095) für die analogen Kanäle.
- **Temperaturwert** in 0,25°C Auflösung (`temp_raw = °C × 4`).

---

# Schritt 2 – Spezifikation des Kommunikationsprotokolls

## 1. Kanaldefinition

### 1.1 Kanalübersicht

| Kanal | Bit | Maske  | Typ | Beschreibung |
| ----- | --- | --- | --- | --- |
| CH0 | 0 | 0x0001 | Digital IN/OUT | z. B. Heater |
| CH1 | 1 | 0x0002 | Digital IN/OUT | z. B. Fan230V |
| CH2 | 2 | 0x0004 | Digital IN/OUT | z. B. Fan230V-Slow |
| CH3 | 3 | 0x0008 | Digital IN/OUT | z. B. Fan12V |
| CH4 | 4 | 0x0010 | Digital IN/OUT | z. B. Lampe |
| CH5 | 5 | 0x0020 | Digital IN/OUT | z. B. Motor |
| CH6 | 6 | 0x0040 | Digital IN/OUT | frei |
| CH7 | 7 | 0x0080 | Digital IN/OUT | frei |
| CH8 | 8 | 0x0100 | Digital IN/OUT | frei |
| CH9 | 9 | 0x0200 | Digital IN/OUT | frei |
| CH10  | 10  | 0x0400 | Digital IN/OUT | frei |
| CH11  | 11  | 0x0800 | Digital IN/OUT | frei |
| CH12  | 12  | 0x1000 | Digital + Analog0 | ADC-Kanal 0 |
| CH13  | 13  | 0x2000 | Digital + Analog1 | ADC-Kanal 1 |
| CH14  | 14  | 0x4000 | Digital + Analog2 | ADC-Kanal 2 |
| CH15  | 15  | 0x8000 | Digital + Analog3 | ADC-Kanal 3 |

---

### 1.2 Digitalmaske (16 Bit)

Eine **16-Bit-Hex-Maske** repräsentiert die digitalen Zustände aller Kanäle:

- `0000` → alle Kanäle LOW  
- `0001` → CH0 HIGH  
- `0019` → CH0 + CH3 + CH4 HIGH  
- `8001` → CH0 und CH15 HIGH  

Immer **4 Hex-Zeichen** senden (z. B. `000F`, `01A3`, etc.).

---

## 2. Analoge Eingänge (4 Kanäle)

Die analogen Messwerte werden vom CLIENT geliefert:

| ADC Input | Kanal | Feldname im Protokoll |
| --- | ----- | --- |
| ADC0 | CH12  | adc0_raw |
| ADC1 | CH13  | adc1_raw |
| ADC2 | CH14  | adc2_raw |
| ADC3 | CH15  | adc3_raw |

Wertebereich: **0–4095**

Die Umrechnung in Spannung (z. B. 0–5 V) erfolgt ausschließlich im HOST.

---

## 3. Temperaturmessung (MAX6675)

- MAX6675 liefert Temperatur in 0,25°C-Schritten.
- Übertragung im Protokoll:

```
temp_raw = °C × 4
```

Beispiele:  
- 25,00°C → `100`  
- 123,75°C → `495`  

---

## 4. UART-Protokollstruktur

Grundstruktur aller Nachrichten:

```
<Sender>;<Command>[;Argument1;Argument2;...]\r\n
```

- **Sender:**  
  - `H` = HOST  
  - `C` = CLIENT  
- **Trennzeichen:** `;`  
- **Ende der Nachricht:** `
`  

---

# 5. Befehle und Antworten

## 5.1 HOST → CLIENT

### 5.1.1 SET – Schreiben der digitalen Kanäle

Setzt den Zustand aller 16 digitalen Kanäle.

```
H;SET;<bitmask16_hex>

```

**Beispiel:**  

Heater (CH0), Fan12V (CH3) und Lampe (CH4) EIN → Maske `0019`

```
H;SET;0019

```

---

### 5.1.2 GET STATUS – Statusanforderung

```
H;GET;STATUS

```

---

### 5.1.3 PING

```
H;PING

```

---

## 5.2 CLIENT → HOST

### 5.2.1 ACK / ERR für SET

Erfolg:

```
C;ACK;SET;<bitmask16_hex>

```

Fehler:

```
C;ERR;SET;<error_code>

```

---

### 5.2.2 STATUS – kompletter Systemstatus

**Erweitertes STATUS-Format:**

```
C;STATUS;<bitmask16_hex>;<adc0_raw>;<adc1_raw>;<adc2_raw>;<adc3_raw>;<temp_raw>

```

**Beispiel:**

```
C;STATUS;0013;1000;2000;3000;4095;100

```

---

### 5.2.3 PONG

Antwort auf `PING`:

```
C;PONG

```

---

# Diagramme
## Sequenz-Diagramm
```mermaid
sequenceDiagram
    participant User as User_Touch
    participant Host as HOST
    participant Client as CLIENT
    participant IO as IO_System
    participant Sensors as Sensoren

    User->>Host: UI toggles channel
    Host->>Host: Update 16-bit mask

    Host->>Client: H_SET_bitmask16_hex
    Client->>Client: Apply mask
    Client->>IO: Update digital outputs
    Client-->>Host: C_ACK_SET_bitmask16_hex

    Host->>Client: H_GET_STATUS
    Client->>Sensors: Read ADC and temperature
    Client-->>Host: C_STATUS_mask_a0_a1_a2_a3_temp

    Host->>Host: Parse status and update UI    
```

## Zustandsdiagramm - HOST

```mermaid
stateDiagram-v2
    [*] --> INIT

    INIT --> IDLE: UART initialisieren\nProtokollzustand zurücksetzen

    state IDLE {
        [*] --> READY
        READY --> READY: UI-Ereignis (Button)\n→ Bitmaske ändern\n→ ggf. SET anstoßen
    }

    IDLE --> SEND_SET: UI-Änderung\n→ neue Bitmaske senden
    SEND_SET --> WAIT_ACK: H;SET;<bitmask>\r\n gesendet

    WAIT_ACK --> IDLE: C;ACK;SET;...\nEmpfangen OK
    WAIT_ACK --> ERROR: C;ERR;SET;...\noder Timeout

    IDLE --> REQUEST_STATUS: Poll-Zyklus\noder nach SET
    REQUEST_STATUS --> WAIT_STATUS: H;GET;STATUS\r\n gesendet

    WAIT_STATUS --> IDLE: C;STATUS;... empfangen\nDaten übernehmen, UI aktualisieren
    WAIT_STATUS --> ERROR: Timeout oder Parserfehler

    ERROR --> IDLE: Fehler quittiert / Reset\nKommunikation neu starten
```

## Zustandsdiagramm - CLIENT
```mermaid
stateDiagram-v2
    [*] --> INIT

    INIT --> IDLE: UART, GPIO, ADC,\nSPI (MAX6675) initialisieren

    state IDLE {
        [*] --> WAIT_CMD
        WAIT_CMD --> WAIT_CMD: Keine Daten / Idle\n(ggf. zyklisch STATUS senden)
    }

    IDLE --> PROCESS_SET: Kommando H;SET;... empfangen\nMaske parsen
    PROCESS_SET --> UPDATE_OUTPUTS: Digitale Ausgänge setzen\nBitmaske anwenden
    UPDATE_OUTPUTS --> SEND_ACK: C;ACK;SET;<bitmask>\r\n
    SEND_ACK --> IDLE

    IDLE --> PROCESS_GET_STATUS: Kommando H;GET;STATUS empfangen
    PROCESS_GET_STATUS --> READ_SENSORS: ADC0–ADC3 + MAX6675 lesen
    READ_SENSORS --> SEND_STATUS: C;STATUS;... senden
    SEND_STATUS --> IDLE

    IDLE --> PROCESS_PING: H;PING\r\n empfangen
    PROCESS_PING --> SEND_PONG: C;PONG\r\n
    SEND_PONG --> IDLE

    IDLE --> ERROR: Parserfehler / ungültiger Befehl
    ERROR --> IDLE: ggf. C;ERR;...\r\n senden\noder nur intern loggen
```

# Ende des Dokuments

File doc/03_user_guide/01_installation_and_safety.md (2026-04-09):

# Installation and Safety

## Critical safety rule

Do not connect USB while the dryer is connected to mains power.

Reason:

- the reused oven power board is mains-related
- the ESP32 electronics can see unsafe potential differences during development
- this can damage the ESP32, the PC or both

Safe options:

- unplug mains before USB work
- use a USB isolator
- use an isolated supply setup

## System overview for installation

The current setup consists of:

- base oven hardware
- reused power board
- `HOST` display controller
- `CLIENT` IO controller

## Installation baseline

The archived installation notes are still available here:

- `doc/archive/pre_reorg_v0.7.1/legacy_docs/filament-silicagel-dryer_installation_v2.md`

That content should later be rewritten into a compact, maintained installation guide once the hardware variant is frozen.

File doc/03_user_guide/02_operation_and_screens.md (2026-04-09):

# Operation and Screens

## Main operating concept

The dryer is operated primarily from the `HOST` touch UI.

The normal workflow is:

1. select a preset or adjust parameters
2. start a drying run
3. monitor current chamber and hotspot temperatures
4. pause, resume or stop as needed

## Main screen

The main screen is the operational center.

It provides:

- runtime and progress
- target and current temperatures
- actuator state icons
- start / stop / pause / resume actions
- fast preset buttons

Behavioral baseline:

- fast preset buttons are intended for stopped state
- door-open conditions can move the system into a waiting state
- the lower action reflects the next useful action, not just raw state text

## Parameter screen

The parameter screen is new in the recent mainline work and currently manages:

- fast shortcut assignment
- heater-curve parameters for preset groups
- display timeout parameters

Saving parameters writes host-side persistent storage and triggers a reboot.

## Screen interaction model

```mermaid
stateDiagram-v2
    [*] --> Stopped
    Stopped --> Running: Start
    Running --> Waiting: Pause
    Running --> Waiting: Door opened
    Waiting --> Running: Resume with closed door
    Running --> Stopped: Stop
    Waiting --> Stopped: Stop
```

## What the user should trust

- chamber temperature is the main process temperature
- hotspot temperature is the safety-oriented reference
- displayed actuator states should reflect client telemetry, not only host intent

## Historic screen deep dives

Previous screen-specific notes remain archived in:

- `doc/archive/pre_reorg_v0.7.1/legacy_docs/screens/`
- `doc/archive/pre_reorg_v0.7.1/legacy_docs/deep_dives/`

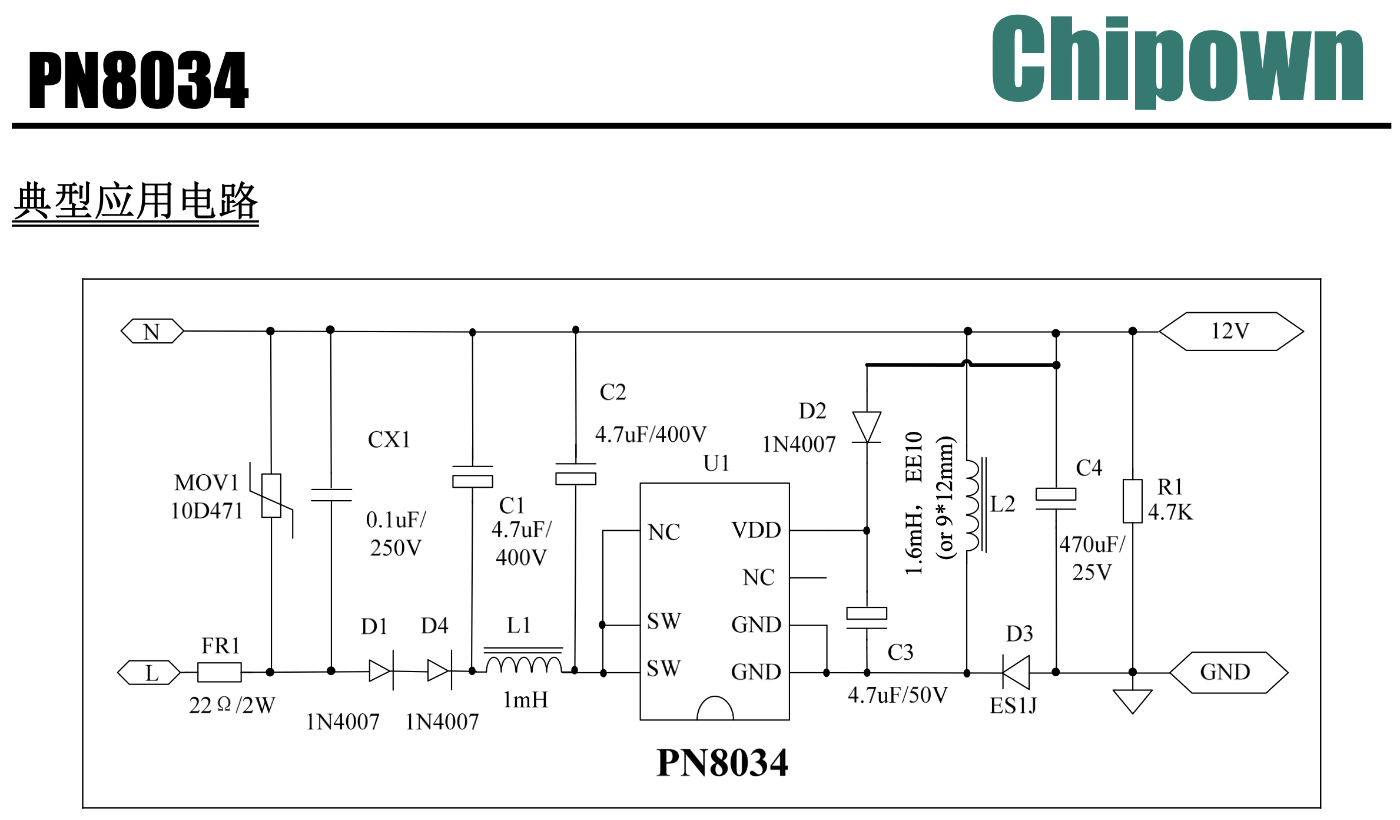
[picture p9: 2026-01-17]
doc/reverse_engineering/PN8034_wiring.png

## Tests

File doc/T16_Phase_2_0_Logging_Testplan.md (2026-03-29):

# T16 Phase 2.0 Logging und Testplan

## Ziel

Phase 2.0 schafft die gemeinsame Grundlage fuer:

- auswertbare UDP-/CSV-Logs im `udp-viewer`
- Trennung zwischen Temperaturdarstellung und Logikdarstellung
- spaetere fachliche Heizkurvenarbeit in Phase 2.x
- reproduzierbare Tests

In diesem Schritt wurde noch keine materialabhaengige Heizstrategie eingefuehrt.
Es geht bewusst zuerst um Beobachtbarkeit und Testbarkeit.

---

## Logging-Zielbild

Es werden zwei Logklassen vorgesehen:

1. `PLOT`
- fuer Temperaturkurven
- fuer Graphen im `udp-viewer`
- numerisch und zeitlich stabil

2. `LOGIC`
- fuer digitale und semantische Zustandsverlaeufe
- fuer Heater/Door/Safety/Mode
- gut lesbar als Zustandsdiagramm oder digitale Spur

---

## Aktueller Scope in T16_Phase_2.0

### Host PLOT

CSV-Prefix:
- `CSV_HOST_TEMP`

Aktuelle Felder:
- `tempChamber_dC`
- `tempHotspot_dC`
- `tempTarget_dC`
- `tempLow_dC`
- `tempHigh_dC`
- `safetyCutoffActive`

Zweck:
- Chamber-Kurve gegen Hotspot-Kurve betrachten
- Target und Hysteresefenster sichtbar machen
- Safety-Ereignisse im selben Zeitkontext sehen

### Host LOGIC

CSV-Prefix:
- `CSV_HOST_LOGIC`

Aktuelle Felder:
- `mode`
- `running`
- `heater_request_on`
- `heater_actual_on`
- `door_open`
- `safetyCutoffActive`
- `commAlive`
- `linkSynced`

Zweck:
- Host-Entscheidung gegen effektiven Heizstatus vergleichen
- Safety- und Kommunikationszustaende im Zeitverlauf sehen

---

## Mermaid Datenfluss

```mermaid
flowchart TD
    A["Client Sensorik + IO"] --> B["STATUS an Host"]
    B --> C["Host RuntimeState"]
    C --> D["CSV_HOST_TEMP"]
    C --> E["CSV_HOST_LOGIC"]
    D --> F["UDP / Serial Log Stream"]
    E --> F
    F --> G["udp-viewer"]
    G --> H["Temperaturgraphen"]
    G --> I["Logik-/State-Spuren"]
```

---

## Testvorgehen

## 1. Automatisierte Tests

### Ziel
Format- und Grundverhalten frueh absichern, noch bevor echte Hardwarelaeufe ausgewertet werden.

### Sinnvolle Testbausteine

- CSV-Format-Tests
  - `CSV_HOST_TEMP` hat konstante Feldanzahl
  - `CSV_HOST_LOGIC` hat konstante Feldanzahl
  - Prefixe sind stabil

- Host-Logiktests
  - Safety wird bei Door Open aktiv
  - Safety wird bei Chamber-Max aktiv
  - Safety wird bei Hotspot-Max aktiv
  - Safety wird bei Overshoot-Cap aktiv
  - `heater_request_on` und `heater_actual_on` verhalten sich erwartbar

- Zustandswechseltests
  - STOPPED -> RUNNING
  - RUNNING -> WAITING
  - RUNNING -> POST
  - RUNNING -> STOPPED

### Ergebnis

Automatisierte Tests sollen nicht die reale Thermik beweisen, aber:
- Formatstabilitaet sichern
- offensichtliche Regressionsfehler frueh finden
- Logdaten fuer den `udp-viewer` kompatibel halten

---

## 2. Manuelle Software-/Integrationspruefung

### Ziel
Vor Hardware-Heiztests sicherstellen, dass Logstroeme plausibel aussehen.

### Schritte

1. Firmware mit aktiviertem UDP-/CSV-Logging starten
2. `udp-viewer` mit laufendem Stream verbinden
3. pruefen, ob `CSV_HOST_TEMP` empfangen wird
4. pruefen, ob `CSV_HOST_LOGIC` empfangen wird
5. Door oeffnen/schliessen und auf Zustandswechsel achten
6. Start/Stop/Wait ausloesen und auf `mode`-Wechsel achten
7. pruefen, ob `heater_request_on` und `heater_actual_on` als getrennte Signale sichtbar sind

---

## 3. Manuelle Hardware-Runtimetests

### Wichtig

Ab den naechsten Phase-2-Schritten werden reale Hardware-Runtimetests sinnvoll und fachlich wichtig.
Insbesondere sobald materialabhaengige Heizstrategie oder Overshoot-Feinheiten veraendert werden.

### Erste sinnvolle Testfaelle

#### Test H1: Kaltstart
- System kalt
- Preset starten
- beobachten:
  - `tempChamberC`
  - `tempHotspotC`
  - `heater_request_on`
  - `heater_actual_on`
  - `safetyCutoffActive`

#### Test H2: Zielnaehe
- auf Zieltemperatur zulaufen
- beobachten:
  - wie frueh der Heater abgeschaltet wird
  - ob Hotspot deutlich vor Chamber ansteigt
  - ob Overshoot sichtbar wird

#### Test H3: Door Open waehrend RUNNING
- waehrend laufender Trocknung Tuer oeffnen
- erwarten:
  - Safety aktiv
  - Heater aus
  - klare Zustandsaenderung in `LOGIC`

#### Test H4: Kommunikationsverlust
- Host/Client-Verbindung stoeren
- erwarten:
  - `commAlive` bzw. `linkSynced` kippen
  - sicherer Zustand sichtbar

#### Test H5: Preset-Vergleich
- spaeter PLA vs. TPU vs. Silica
- erwarten:
  - unterscheidbare Temperatur- und Logikverlaeufe

---

## Erfolgskriterien fuer T16_Phase_2.0

- Host erzeugt getrennte `PLOT`- und `LOGIC`-Logs
- Feldschema ist fuer den `udp-viewer` stabil auswertbar
- automatisierte Tests koennen spaeter darauf aufsetzen
- manuelle Hardwaretests sind klar vorbereitet

---

## Betroffene Dateien

- [`include/log_csv.h`](/Users/bernhardklein/workspace/arduino/esp32/FilamentSilicatDryer_480x480/include/log_csv.h)
- [`src/app/oven/oven.cpp`](/Users/bernhardklein/workspace/arduino/esp32/FilamentSilicatDryer_480x480/src/app/oven/oven.cpp)

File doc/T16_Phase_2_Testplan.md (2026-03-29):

# T16 Phase 2 Testplan

## Ziel

Die neue Host-Heizstrategie soll unter realen Bedingungen beobachtet und gegen die fachlichen Risiken abgesichert werden:

- Overshoot bei Filament minimieren
- Silica robust und zuegig aufheizen
- Safety-Regeln jederzeit wirksam halten
- Stages und Material-Policy im Log sichtbar machen

## Automatisiert sinnvoll

### Build-Validierung

- `pio run -e host_esp32s3_st7701`
- `pio run -e client_esp32_wroom`

### Spaeter sinnvoll zu ergaenzen

- reine Host-Tests fuer:
  - Stage-Uebergang `BULK_HEAT -> APPROACH -> HOLD`
  - Policy-Auswahl `FILAMENT` vs. `SILICA`
  - Safety-Cutoff bei Door / Chamber / Hotspot / Overshoot

## Manuelle Hardwaretests

### Test 1: Filament, kalter Start

- Preset `PLA` oder `TPU` waehlen
- Ofen im kalten Zustand starten
- beobachten:
  - Stage startet in `BULK_HEAT`
  - spaeter Wechsel nach `APPROACH`
  - nahe Soll Wechsel nach `HOLD`
  - kein unruhiges Relais-Klappern

### Test 2: Filament nahe Soll

- Ofen bereits vorgewaermt
- Filament-Preset mit niedrigerem Target waehlen
- beobachten:
  - Heizer startet nicht blind aggressiv
  - Regelung bleibt vorsichtig
  - kein grober Overshoot ueber Soll

### Test 3: Silica

- Preset `SILICA` waehlen
- Lauf bis in den Zielbereich
- beobachten:
  - groessere Heizfenster als bei Filament
  - trotzdem Safety wirksam
  - Stage-Wechsel sichtbar

### Test 4: Door Safety

- waehrend `RUNNING` Tuer oeffnen
- erwarten:
  - Heater Request faellt ab
  - Safety aktiv
  - Door im Log sichtbar

### Test 5: Communication / Sync

- Host/Client kurzzeitig stoeren oder neu starten
- erwarten:
  - `commAlive` / `linkSynced` reagieren sichtbar
  - kein unkontrolliertes Heizen

## Relevante Logfelder

### HOST_TEMP

- chamber
- hotspot
- target
- low
- high
- safety

### HOST_LOGIC

- mode
- running
- heater_request_on
- heater_actual_on
- door
- safety
- commAlive
- linkSynced
- materialClass
- heaterStage

## Abnahmekriterien fuer die naechste Iteration

- Filament zeigt keinen groben, laenger anstehenden Overshoot
- Stage-Uebergaenge sind im Log plausibel
- Silica verwendet die getrennte Policy sichtbar
- Safety schaltet reproduzierbar ab
- Relais bleibt schalttechnisch ruhig

## Testhinweis

Ab diesem Phasenstand sind echte Hardware-Runtimetests nicht nur sinnvoll, sondern fuer weiteres Heizkurven-Tuning notwendig. Reine Builds reichen ab hier nicht mehr aus, um die fachliche Qualitaet der Heizkurve zu bewerten.

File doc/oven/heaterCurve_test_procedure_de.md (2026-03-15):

# T15 HeaterCurve – Testvorgehen zur empirischen Parameterermittlung

## Ziel dieses Dokuments

Dieses Dokument beschreibt die **empirische Vorgehensweise**, mit der die entscheidenden HeaterCurve-Parameter bestimmt werden sollen.

Wichtigster Grundsatz:

> **Nie mehrere Regelparameter gleichzeitig verändern.**

Nur wenn immer **genau ein Parameterblock** verändert wird, kann später nachvollzogen werden:

- welcher Parameter welchen Einfluss hat
- welche Wechselwirkung zwischen den Parametern besteht
- wie die Parameter sauber aufeinander abgestimmt werden

---

# Grundprinzip der Parametrierung

Die spätere Heizkurve hängt im Wesentlichen von drei Gruppen von Parametern ab:

1. **thermische Systemparameter**
   - z. B. Nachlaufzeit (`tau`)
   - Ansprechverhalten der Chamber
   - Reaktionsgeschwindigkeit des Hotspots

2. **Sicherheits- und Frühwarnparameter**
   - z. B. `hotspot_limit`
   - `hotspot_delta_limit`

3. **Regelparameter**
   - z. B. HOLD-Duty
   - APPROACH-Abbremsung
   - Slope-Filter

Diese Parameter dürfen **nicht gleichzeitig** optimiert werden.

Die richtige Reihenfolge ist:

1. **System verstehen**
2. **Sicherheitsgrenzen festlegen**
3. **Regelverhalten abstimmen**
4. **Feintuning**

---

# Wichtige Regel

## Eine Testreihe = nur ein Ziel

Beispiel:

### erlaubt
- nur `tau` bestimmen
- nur `hotspot_limit` bestimmen
- nur `hold_duty` bestimmen

### nicht erlaubt
- gleichzeitig `tau`, `hotspot_limit` und `hold_duty` ändern

---

# Feste Randbedingungen für alle Tests

Damit Ergebnisse vergleichbar bleiben, müssen folgende Bedingungen pro Testserie möglichst konstant bleiben:

- gleiche Hardware
- gleiche Sensorposition
- gleiches Gehäuse / gleiche Türstellung
- gleiche Luftströmung / Lüfterzustand
- gleiche PWM-Frequenz
- gleiche Umgebungstemperatur
- möglichst gleiche Ausgangstemperatur vor Testbeginn

Zusätzlich sollte jeder Test dokumentieren:

- Datum / Uhrzeit
- Starttemperatur Chamber
- Starttemperatur Hotspot
- Türstatus
- verwendete Parameter
- Besonderheiten / Beobachtungen

---

# Empfohlene Reihenfolge der empirischen Tests

## Phase 1 – Sensorik und Messpfad verifizieren

Ziel:
- sicherstellen, dass alle Messwerte plausibel sind

Zu prüfen:
- Chamber zeigt bei Raumtemperatur plausible Werte
- Hotspot zeigt bei Raumtemperatur plausible Werte
- Handwärme / leichte Erwärmung erzeugt nachvollziehbare Änderung
- Door open / closed wird korrekt erkannt
- Heater OFF / ON ist im Log eindeutig sichtbar

### Ergebnis dieser Phase
Erst wenn diese Basis korrekt funktioniert, dürfen weitere Tests erfolgen.

---

## Phase 2 – Thermisches Grundverhalten des Systems bestimmen

Diese Phase dient dazu, das System selbst zu verstehen, **noch ohne echte Regelung**.

---

### Test 2.1 – Reine Aufheizreaktion

Ziel:
- verstehen, wie schnell Hotspot und Chamber bei konstanter Heizleistung reagieren

Vorgehen:
1. Chamber auf möglichst definierte Starttemperatur bringen
2. Heater mit fester Leistung einschalten
3. Temperaturen loggen
4. Test vor kritischen Bereichen beenden

Zu beobachten:
- wie schnell steigt Hotspot?
- wann beginnt Chamber messbar zu steigen?
- wie groß ist die zeitliche Verzögerung zwischen Hotspot und Chamber?
- wie groß wird `hotspot - chamber` während des Aufheizens?

### Ergebnis
Diese Messung liefert:
- erstes Gefühl für Systemträgheit
- erstes Gefühl für typische Hotspot-Deltas
- erste Abschätzung, ab wann Hotspot kritisch wird

**In dieser Phase noch keine Parameter anpassen.**

---

### Test 2.2 – Nachlauf nach Heater-OFF

Ziel:
- Bestimmung von `tau` bzw. der thermischen Nachlaufzeit

Vorgehen:
1. System bis in die Nähe des Zielbereichs aufheizen
2. Heater zu einem definierten Zeitpunkt abschalten
3. Temperaturen weiter loggen, bis Chamber ihr Maximum erreicht
4. Zeit und Temperaturanstieg nach Heater-OFF erfassen

Zu messen:
- Chamber bei Abschaltzeitpunkt
- Chamber-Maximum nach Abschalten
- Zeit bis zum Maximum
- Hotspot-Abfall nach Heater-OFF

Beispiel:

- Heater OFF bei 40.0°C Chamber
- Chamber steigt weiter bis 43.8°C
- Maximum nach 68 s erreicht

### Ergebnis
Daraus wird abgeleitet:

- wie stark Chamber typischerweise nachläuft
- wie lange der Nachlauf dauert
- daraus folgt ein **erster Schätzwert für `tau`**

Wichtig:
`tau` wird **vor** dem Hotspot-Limit sauber bestimmt, weil `tau` direkt beschreibt, wie aggressiv die Vorhersage arbeiten muss.

---

# Warum tau zuerst bestimmt werden muss

`hotspot_limit` ist kein isolierter Parameter.

Wenn `tau` zu klein gewählt wird:
- der Algorithmus unterschätzt den Nachlauf
- man würde ein künstlich zu niedriges Hotspot-Limit brauchen

Wenn `tau` zu groß gewählt wird:
- der Algorithmus wird zu vorsichtig
- man würde ein unnötig hohes oder instabiles Hotspot-Limit ableiten

Deshalb gilt:

> **Zuerst tau bestimmen, danach erst hotspot_limit abstimmen.**

---

## Phase 3 – Sicherheits- und Frühwarnparameter bestimmen

---

### Test 3.1 – Hotspot-Verhalten bei bekanntem tau

Voraussetzung:
- `tau` ist bereits grob bekannt

Ziel:
- Hotspot als Frühwarnindikator kalibrieren

Vorgehen:
1. mit festem `tau` arbeiten
2. Chamber auf mehrere Zielbereiche fahren
3. bei jeder Fahrt beobachten:
   - wie hoch wird Hotspot?
   - wie groß wird `hotspot - chamber`?
   - ab welchem Wert beginnt Chamber später zuverlässig zu überschwingen?

Zu erfassen:
- Hotspot absolut
- Hotspot-Delta
- resultierendes Chamber-Verhalten
- ob Overshoot auftritt

### Ergebnis
Daraus werden zwei Parameter abgeleitet:

#### a) `hotspot_limit`
Absolute Hotspot-Grenze

#### b) `hotspot_delta_limit`
Grenze für:

`hotspot - chamber`

Wichtig:
Erst wenn `tau` schon sinnvoll gewählt wurde, haben diese beiden Werte echte Aussagekraft.

---

### Test 3.2 – Sicherheitsgrenze konservativ festlegen

Nachdem erste Hotspot-Messungen vorliegen, wird zunächst ein **konservativer Default** gesetzt.

Beispiel:

- beobachteter problematischer Bereich: 95°C Hotspot
- erster Arbeitswert:
  `hotspot_limit = 90°C`

Analog für Delta:

- problematisch ab 32°C
- erster Arbeitswert:
  `hotspot_delta_limit = 25°C`

### Ziel
Nicht gleich „perfekt optimieren“, sondern erst einmal einen **sicheren Startwert** festlegen.

---

## Phase 4 – Regelparameter im Zielbereich bestimmen

Erst jetzt wird die eigentliche Regelung fein abgestimmt.

---

### Test 4.1 – APPROACH-Verhalten

Ziel:
- bestimmen, wie früh und wie stark vor dem Ziel gebremst werden muss

Vorgehen:
1. `tau` und Hotspot-Limits bleiben fix
2. Start deutlich unter Ziel
3. Regelung läuft in den Zielbereich
4. nur APPROACH-bezogene Parameter anpassen

Zu beobachten:
- wird zu spät abgeschaltet?
- wird zu früh abgeschaltet?
- bleibt die Chamber unter der Obergrenze?
- fällt sie unnötig weit unter den Zielbereich zurück?

### Typische Stellgrößen
- APPROACH duty scaling
- APPROACH threshold
- predictive cutoff aggressiveness

Wichtig:
In dieser Phase **keine Änderung an tau oder hotspot_limit**.

---

### Test 4.2 – HOLD-Verhalten

Ziel:
- stabile Temperaturhaltung im Zielband

Vorgehen:
1. `tau`, Hotspot-Limits und APPROACH bleiben fix
2. System in den Zielbereich bringen
3. HOLD-Modus über längere Zeit beobachten

Zu beobachten:
- wie stark pendelt die Chamber?
- wie oft wird nachgeheizt?
- wie hoch muss die minimale Heizleistung sein?
- wird das Zielband sicher eingehalten?

### Typische Stellgrößen
- `holdWindowMs`
- `minDutyHoldPct`
- `maxDutyHoldPct`

Wichtig:
Hier keine Änderung mehr an den vorher bestimmten Parametern.

---

## Phase 5 – Gesamtsystem validieren

Erst wenn alle Einzelparameterblöcke sinnvoll bestimmt wurden, erfolgt die kombinierte Validierung.

Ziel:
- prüfen, ob das System als Ganzes stabil arbeitet

Testarten:
1. Kaltstart auf Zieltemperatur
2. Wiederanlauf aus warmem Zustand
3. längeres Halten
4. Door open während laufender Regelung
5. Test verschiedener Zieltemperaturen

### Bewertung
Das System ist gut abgestimmt, wenn:

- das Zielband zuverlässig eingehalten wird
- Overshoot innerhalb der Vorgabe bleibt
- keine unnötigen starken Oszillationen auftreten
- Hotspot unter Kontrolle bleibt
- Safety-Verhalten reproduzierbar ist

---

# Konkrete Reihenfolge der Parameterfestlegung

Die Parameter sollten in genau dieser Reihenfolge bestimmt werden:

## Block A – nicht ändern, nur beobachten
- Sensorik
- Rohwerte
- Temperaturplausibilität
- Hotspot/Chamber Verzögerung

## Block B – zuerst bestimmen
- `tau`

## Block C – danach bestimmen
- `hotspot_limit`
- `hotspot_delta_limit`

## Block D – danach bestimmen
- `slope_filter_alpha`

## Block E – danach bestimmen
- APPROACH-Parameter

## Block F – zuletzt bestimmen
- HOLD-Parameter
  - `holdWindowMs`
  - `minDutyHoldPct`
  - `maxDutyHoldPct`

---

# Warum diese Reihenfolge wichtig ist

Wenn man z. B. zuerst `hotspot_limit` tuned und `tau` später ändert, dann ist der alte Hotspot-Wert praktisch wertlos, weil sich die Vorhersagelogik geändert hat.

Ebenso gilt:
- wenn HOLD noch nicht stabil ist, kann man APPROACH schlecht bewerten
- wenn Hotspot-Limits unklar sind, kann man die eigentliche Regelung nicht sinnvoll abstimmen

Darum ist die Reihenfolge zwingend.

---

# Praktische Testempfehlung

Für jeden Testlauf sollte eine kurze Test-ID vergeben werden.

Beispiel:

`T15-Run-001`

Dokumentieren:

- Zieltemperatur
- Starttemperatur
- aktive Parameter
- Testzweck
- Beobachtung
- Ergebnis

Beispiel:

## T15-Run-014
- Ziel: tau bestimmen
- Start: 22°C
- Heater fest eingeschaltet bis 40°C
- Heater OFF bei 40°C
- Peak: 43.6°C nach 64 s

Ergebnis:
- erster tau-Arbeitswert: 60 s

---

# Logging für die Parameterermittlung

Für jeden Lauf sollten mindestens diese Werte geloggt werden:

- Zeitstempel
- Door Zustand
- Chamber Temperatur
- Hotspot Temperatur
- Heater Duty
- Controller Mode
- Chamber Slope
- Predicted Chamber Temperatur
- Safety Reasons

Ergänzend hilfreich:
- raw ADC
- mV
- Ohm

---

# Empfohlene Vorgehensweise für den Start

## Startwert-Strategie

Beim ersten aktiven Test:

1. konservativen `tau` setzen
2. konservatives `hotspot_limit` setzen
3. konservatives `hotspot_delta_limit` setzen
4. Regelung vorsichtig starten
5. nur beobachten
6. dann anhand der Logs gezielt einen Parameterblock anpassen

Beispiel Startwerte:
- `tau = 60 s`
- `hotspot_limit = 90°C`
- `hotspot_delta_limit = 25°C`

Diese Werte sind **nicht final**, sondern nur sichere erste Arbeitswerte.

---

# Zusammenfassung

Die wichtigste Regel für T15 lautet:

> **Zuerst das System verstehen, dann die Sicherheitsgrenzen festlegen, erst danach die eigentliche Regelung abstimmen.**

Die korrekte Reihenfolge ist:

1. Sensorik verifizieren
2. thermischen Nachlauf (`tau`) bestimmen
3. Hotspot-Grenzen bestimmen
4. Slope-Filter bestimmen
5. APPROACH abstimmen
6. HOLD abstimmen
7. Gesamtsystem validieren

So bleibt jederzeit nachvollziehbar, welcher Parameter welchen Einfluss auf die Heizkurve und das Overshoot-Verhalten hat.

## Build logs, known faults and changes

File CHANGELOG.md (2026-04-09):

# Changelog

## Unreleased

- added a second PlatformIO environment for `esp32-s3-devkitc-1`
- moved shared PlatformIO settings into a global `[env]` block
- both board targets now use the same UDP logging, CSV logging and client log flags
- demo loop currently emits logs faster, which makes testing with `udp-viewer` easier

## 0.7.2 - 2026-04-09

- Dokumentation auf Basis des aktuellen `main`-Stands neu strukturiert
- bisherige Dokumente und Assets in `doc/archive/pre_reorg_v0.7.1/legacy_docs/` archiviert
- neue aktive Bereiche fuer Hardware, Softwarearchitektur und User Guide aufgebaut
- Mermaid-Diagramme fuer Host-, Client- und Protokollarchitektur ergänzt
- README und README_EN auf die neue Dokumentationsstruktur umgestellt

## 0.7.1 - 2026-04-09

- `feature/small_enhancements` in `main` migriert
- neuer hostseitiger Screen `Parameter` ersetzt den ungenutzten LOG-Screen
- Fast-Shortcut-Zuordnung der vier Filament-Tasten ist jetzt konfigurierbar und NVM-persistent
- Heater-Curve-Parameter der Presets `45C`, `60C`, `80C`, `100C` sind jetzt hostseitig konfigurierbar und NVM-persistent
- `SAVE` und `RESET` schreiben den aktuellen Stand in NVM und fuehren danach einen Reboot aus
- `SAVE` und `RESET` besitzen Sicherheitsabfragen im Parameterscreen
- neuer Parameterblock `Display timeout` mit `Dimmfaktor (%)` und `Dimm-Timeout (min)`
- Display-Dimmen ist hostseitig konfigurierbar, wird in NVM gespeichert und nach Reboot wieder geladen
- der erste Touch nach gedimmtem Display hellt nur auf und loest keine UI-Aktion aus
- Parameterscreen ist per Swipe nur erreichbar, wenn das System nicht `RUNNING` ist
- README, README_EN und Screen-Dokumentation aktualisiert

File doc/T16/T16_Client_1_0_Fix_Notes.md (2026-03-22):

# T16.Client.1.0 – Fix / echte Sensor-Migration

Ursache des aktuellen Verhaltens:
- ADS1115 wird zwar gefunden
- aber STATUS liefert `adc=[0,0,0,0]` und `-32768`
- damit ist die neue produktive Sensorik noch nicht wirklich angebunden

Das ist mein Fehler aus dem letzten Schritt:
- der vorherige Patch war strukturell, aber noch nicht vollständig fachlich migriert

## Einspielen

Dateien aus diesem ZIP:
- `include/client/sensor_ntc.h`
- `src/client/sensor_ntc.cpp`

## Zusätzliche Änderungen in `src/client/FSD_Client.cpp`

### 1) Include ergänzen
Direkt nach:
```cpp
#include "sensors/ads1115_config.h"
```
ergänzen:
```cpp
#include "client/sensor_ntc.h"
```

### 2) Funktion `isDoorOpen()` ersetzen
Durch:
```cpp
static bool isDoorOpen() {
    const bool now = sensor_ntc::is_door_open();

    static bool last = false;
    if (now != last) {
        CLIENT_INFO("[DOOR] state=%s\n", now ? "OPEN" : "CLOSED");
        last = now;
    }
    return now;
}
```

### 3) `fillStatusCallback(...)` komplett ersetzen
Durch:
```cpp
static void fillStatusCallback(ProtocolStatus &st) {
    st.outputsMask = g_effectiveMask;

    const bool door_open = sensor_ntc::is_door_open();
    if (door_open) {
        st.outputsMask |= (1u << OUTPUT_BIT_MASK_8BIT::BIT_DOOR);
    } else {
        st.outputsMask &= ~(1u << OUTPUT_BIT_MASK_8BIT::BIT_DOOR);
    }

    sensor_ntc::sample_temperatures();
    const sensor_ntc::Sample &sample = sensor_ntc::get_sample();

    st.adcRaw[0] = sample.rawHotspot;
    st.adcRaw[1] = sample.rawChamber;
    st.adcRaw[2] = 0;
    st.adcRaw[3] = 0;

    st.tempHotspot_dC = sample.hotValid ? sample.hot_dC : ntc::TEMP_INVALID_DC;
    st.tempChamber_dC =
        (sample.cha_dC == ntc::TEMP_INVALID_DC) ? ntc::TEMP_INVALID_DC : sample.cha_dC;
}
```

### 4) ADS1115-Init in `setup()` ersetzen
Den bisherigen Block unter:
```cpp
#if ENABLE_INTERNAL_NTC
...
#endif
```
ersetzen durch:
```cpp
#if ENABLE_INTERNAL_NTC
    sensor_ntc::init_i2c_and_ads();
#endif
```

### 5) Door-Init-Log am Ende von `setup()` ersetzen
Den bisherigen manuellen Door-Init-Log ersetzen durch:
```cpp
    sensor_ntc::init_door();
```

## Erwartung nach dem Fix
- ADS1115 wird wie bisher gefunden
- Türstatus bleibt korrekt
- `adcRaw[0]` und `adcRaw[1]` sind nicht mehr 0
- `tempChamber_dC` wird plausibel
- `tempHotspot_dC` wird plausibel, sofern der Hotspot-Messpfad elektrisch gültig ist

## Tests
1. HOST Build
2. CLIENT Build
3. Bootlog:
   - `ADS1115 found`
   - `DOOR init done`
4. STATUS prüfen:
   - `adc=[x,y,0,0]` mit echten Werten
   - `tempChamber_dC != -32768`
5. Tür öffnen/schließen:
   - DOOR Bit weiterhin korrekt

## Commit
`T16.Client.1.0 migrate real dual-NTC sensor path into client`

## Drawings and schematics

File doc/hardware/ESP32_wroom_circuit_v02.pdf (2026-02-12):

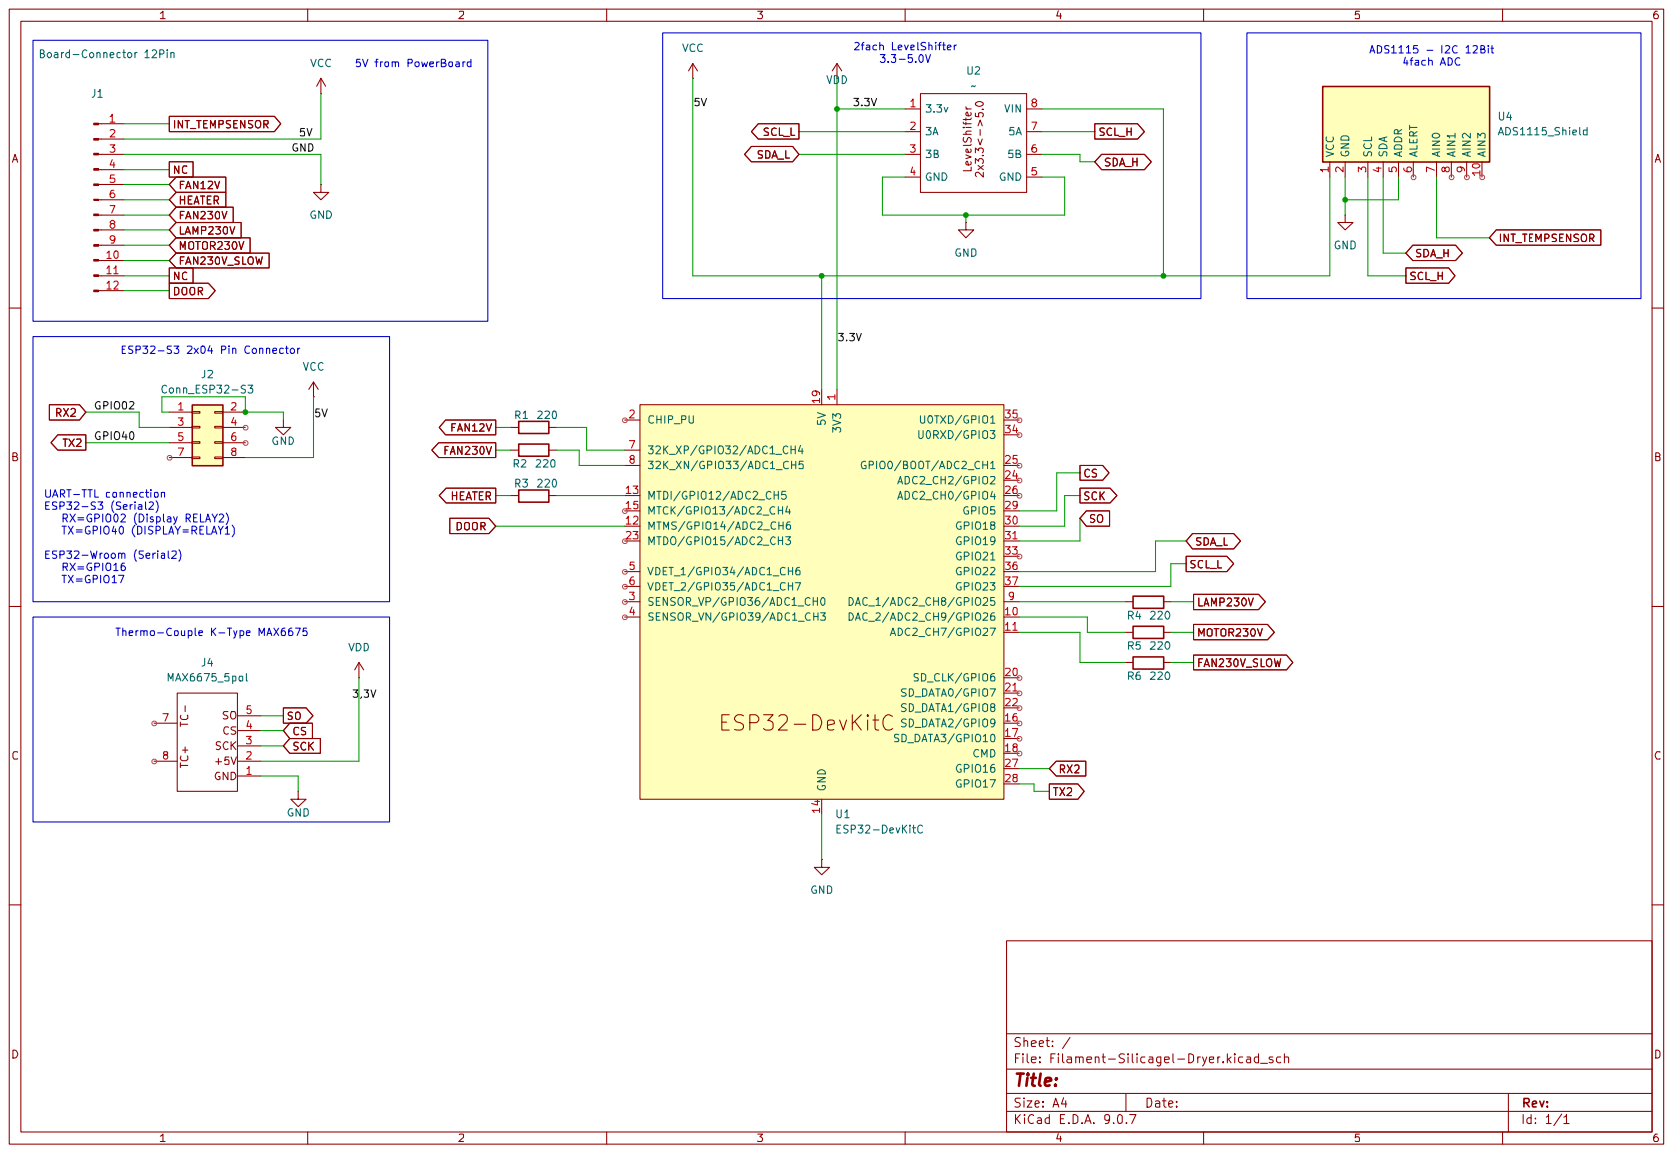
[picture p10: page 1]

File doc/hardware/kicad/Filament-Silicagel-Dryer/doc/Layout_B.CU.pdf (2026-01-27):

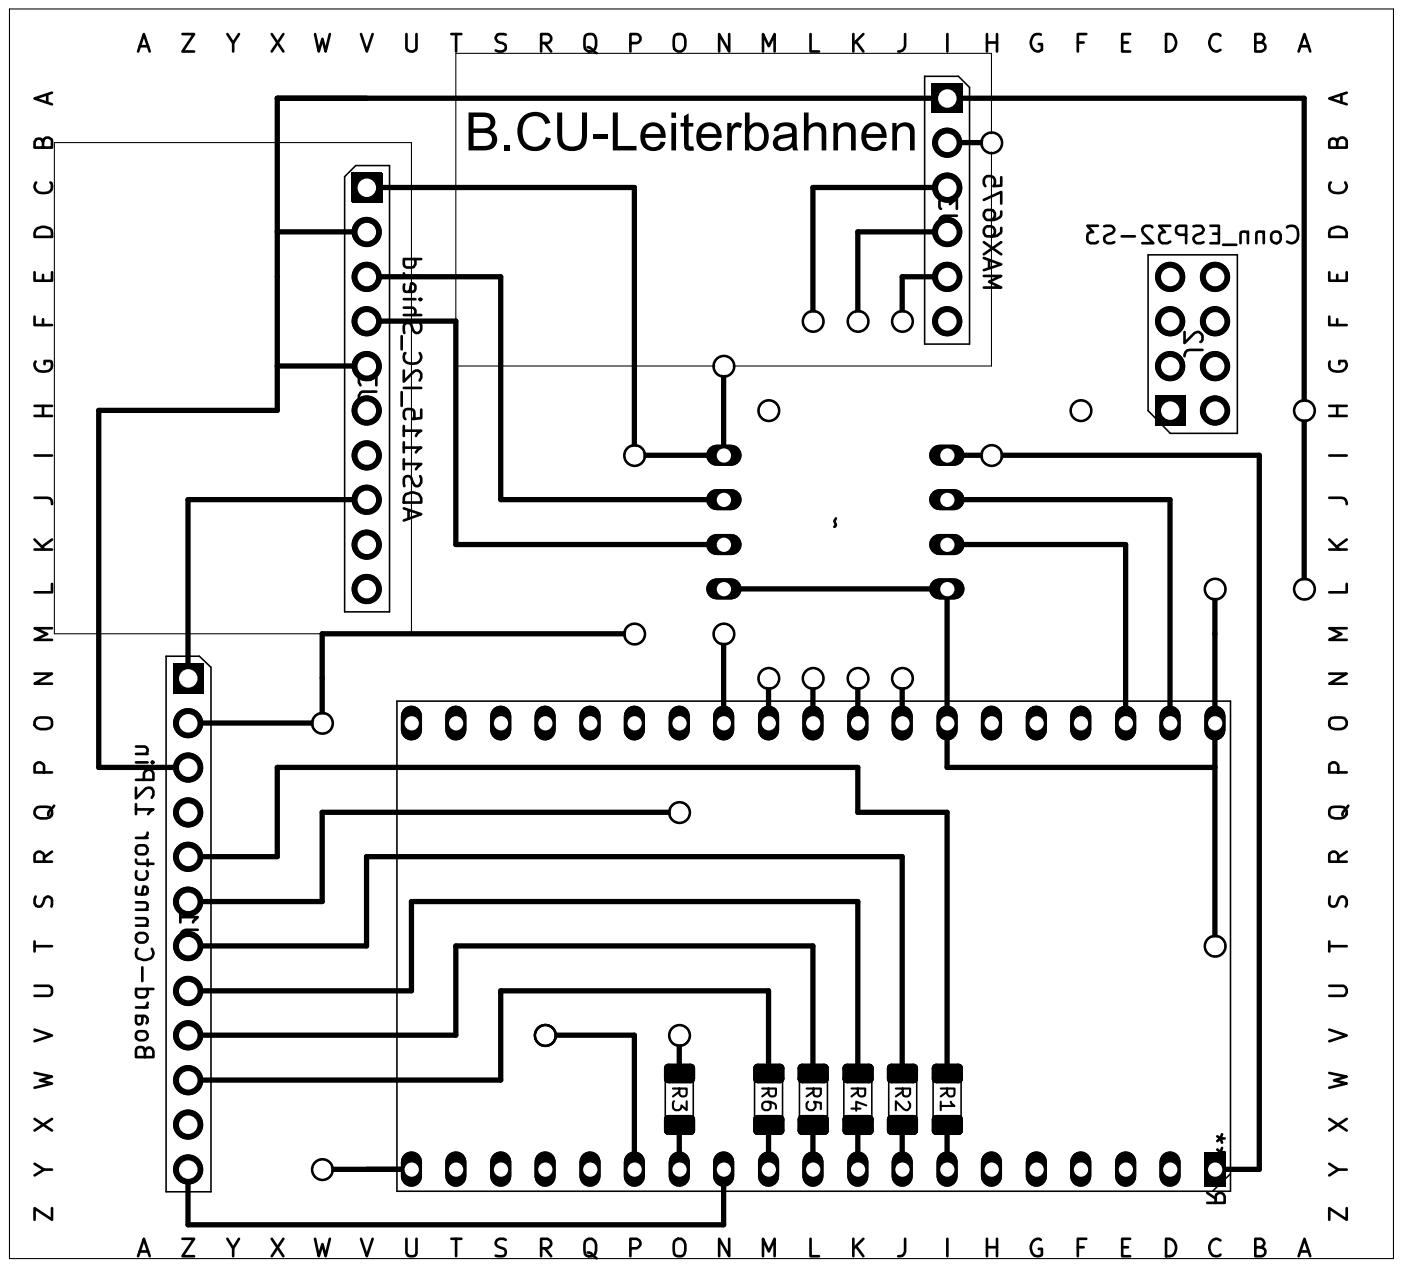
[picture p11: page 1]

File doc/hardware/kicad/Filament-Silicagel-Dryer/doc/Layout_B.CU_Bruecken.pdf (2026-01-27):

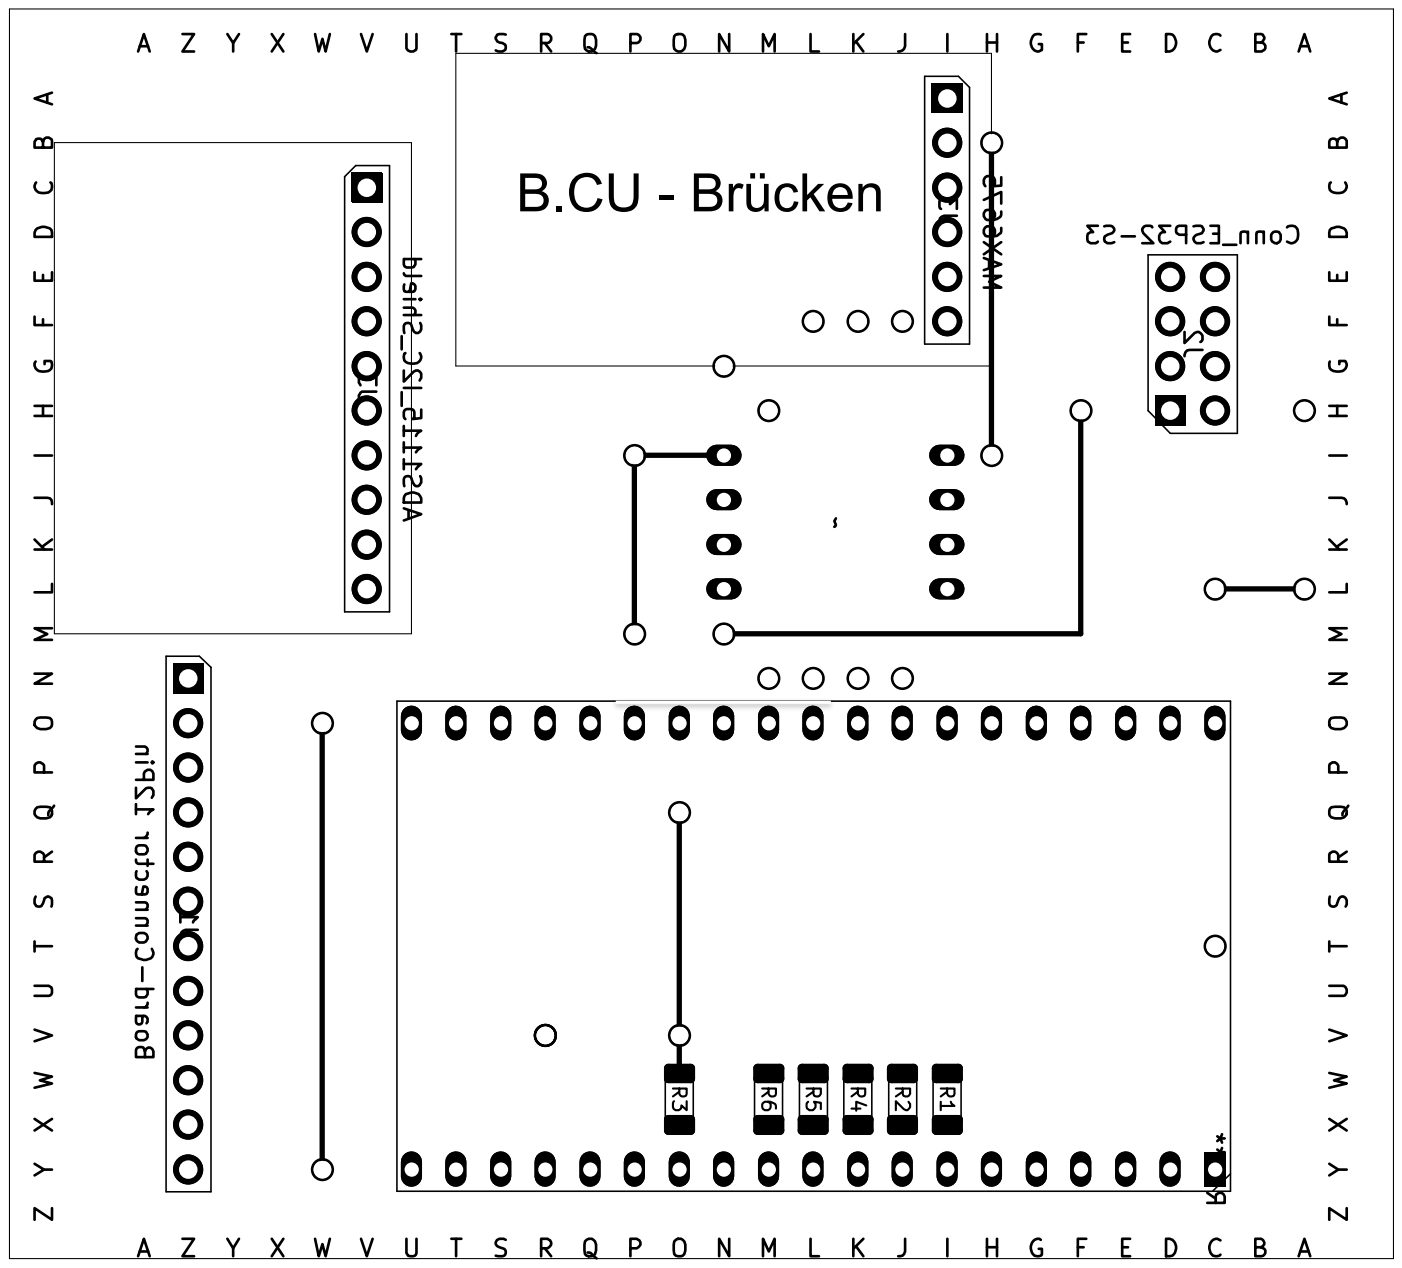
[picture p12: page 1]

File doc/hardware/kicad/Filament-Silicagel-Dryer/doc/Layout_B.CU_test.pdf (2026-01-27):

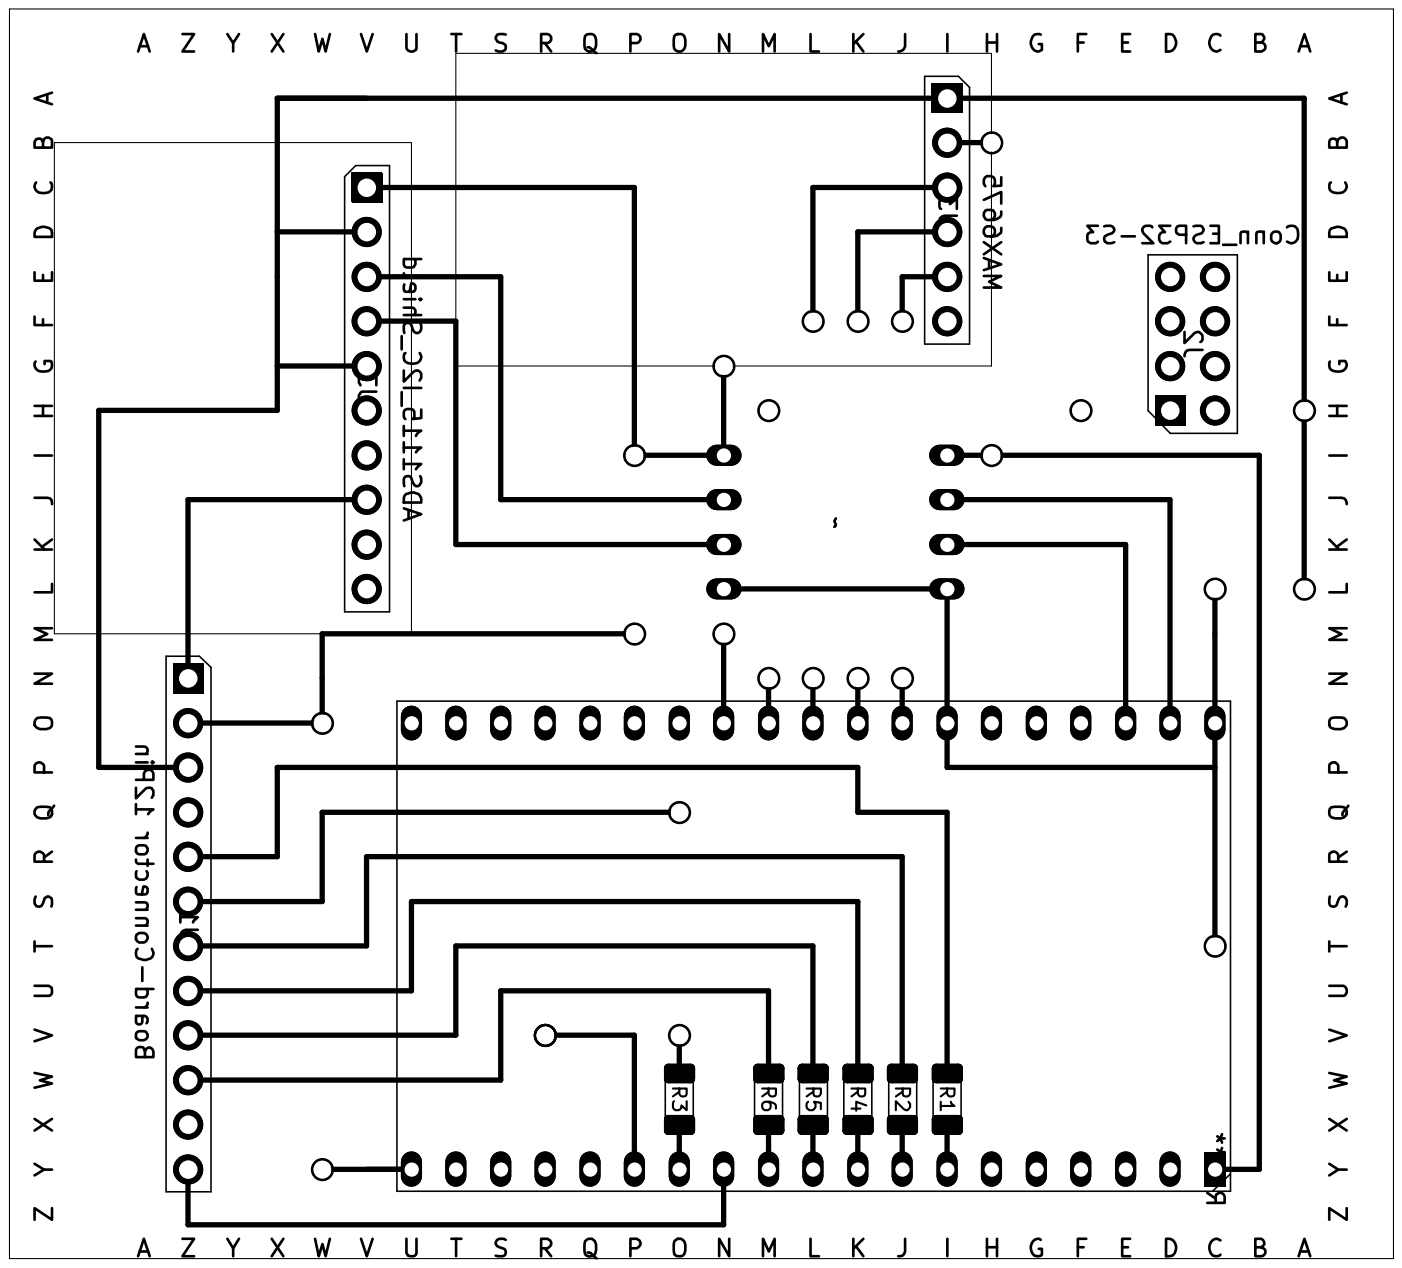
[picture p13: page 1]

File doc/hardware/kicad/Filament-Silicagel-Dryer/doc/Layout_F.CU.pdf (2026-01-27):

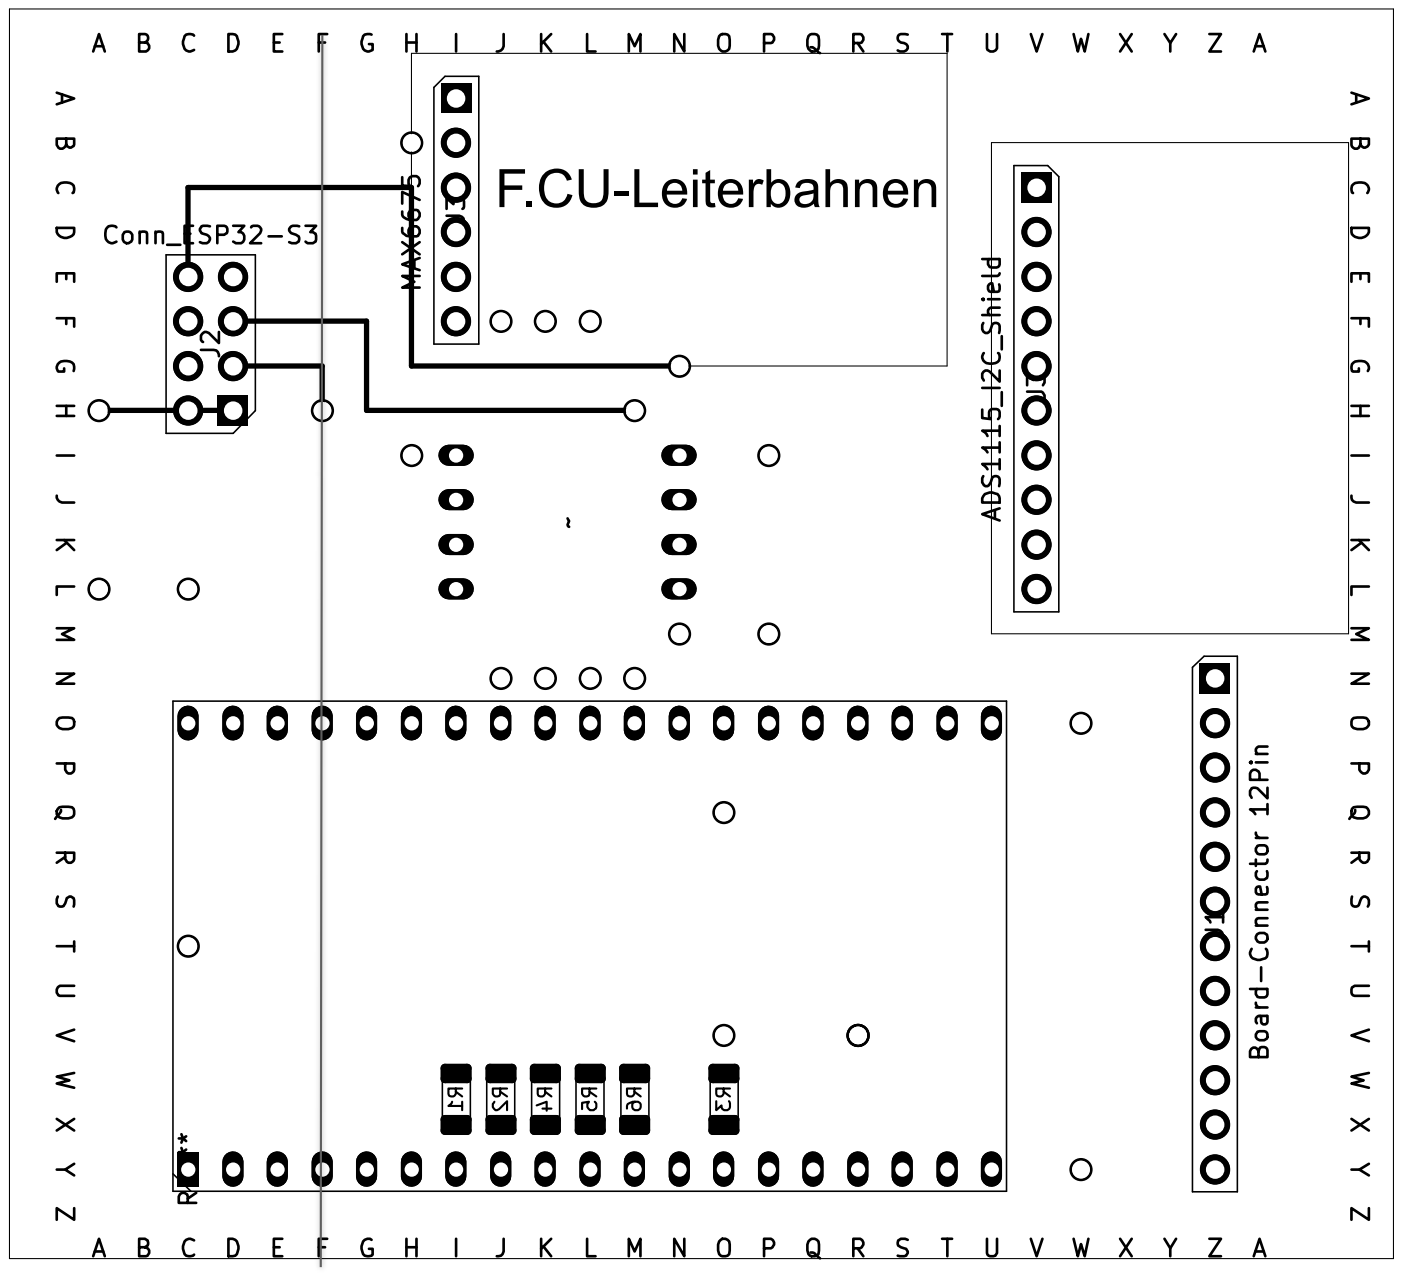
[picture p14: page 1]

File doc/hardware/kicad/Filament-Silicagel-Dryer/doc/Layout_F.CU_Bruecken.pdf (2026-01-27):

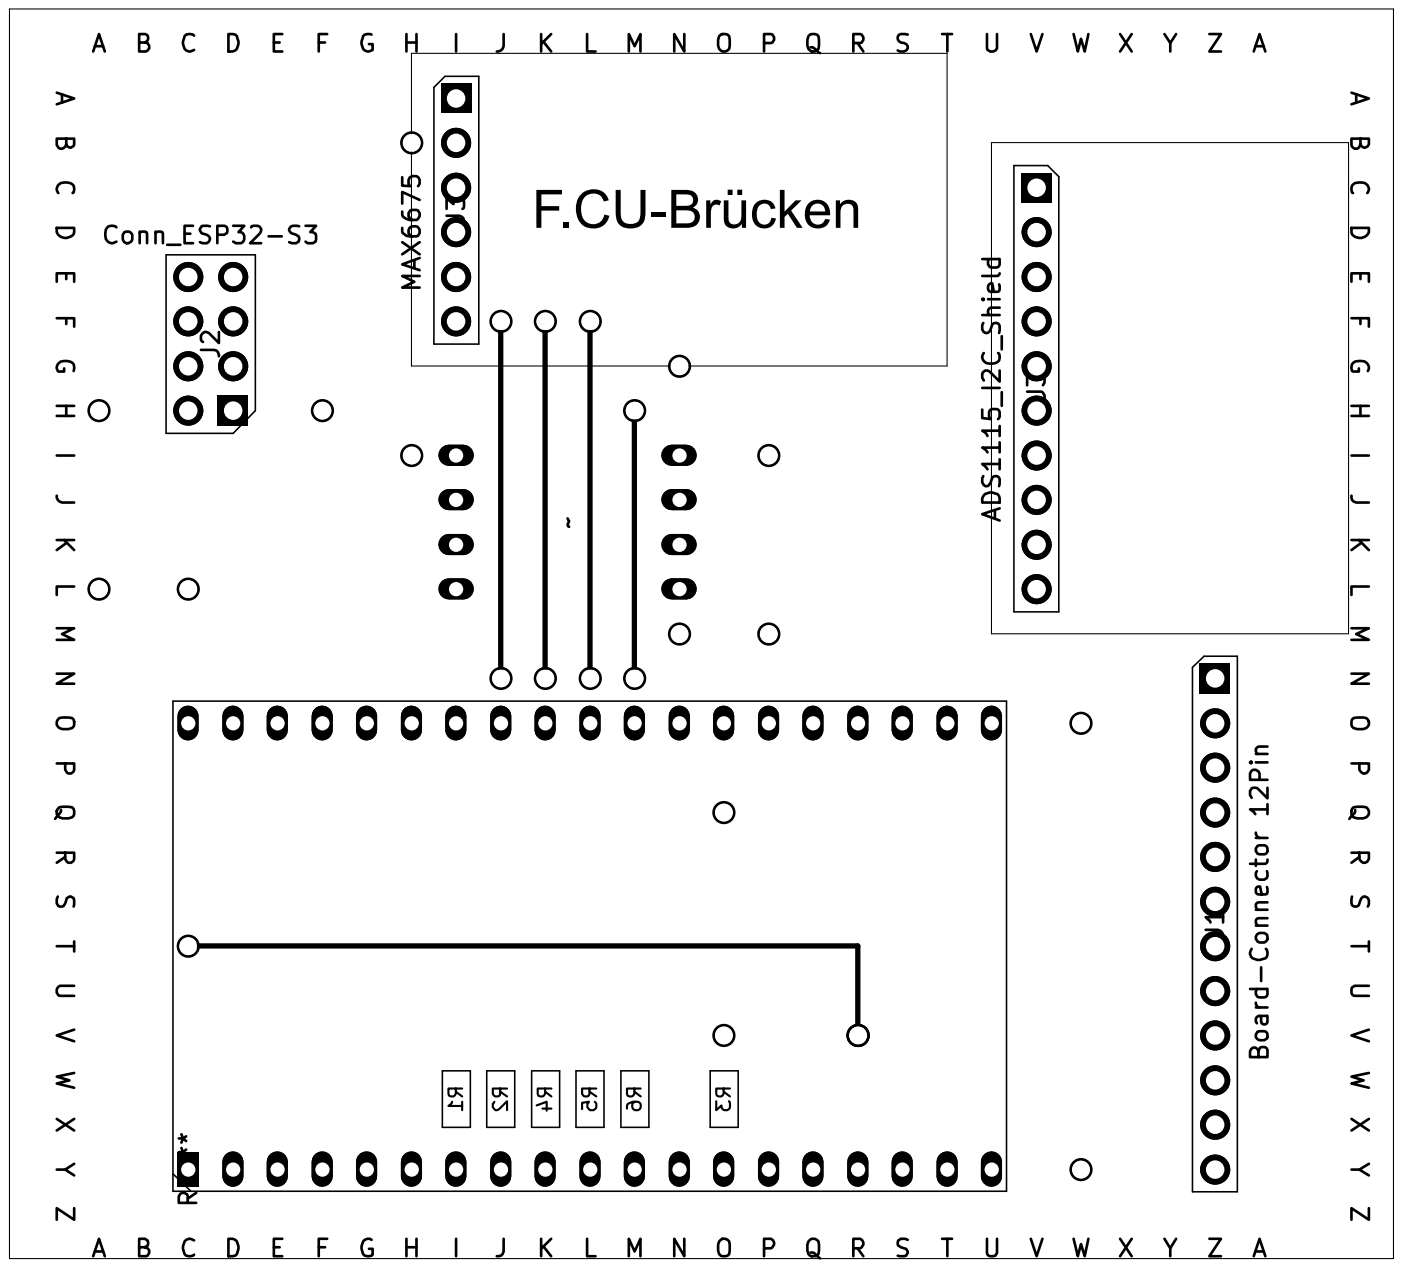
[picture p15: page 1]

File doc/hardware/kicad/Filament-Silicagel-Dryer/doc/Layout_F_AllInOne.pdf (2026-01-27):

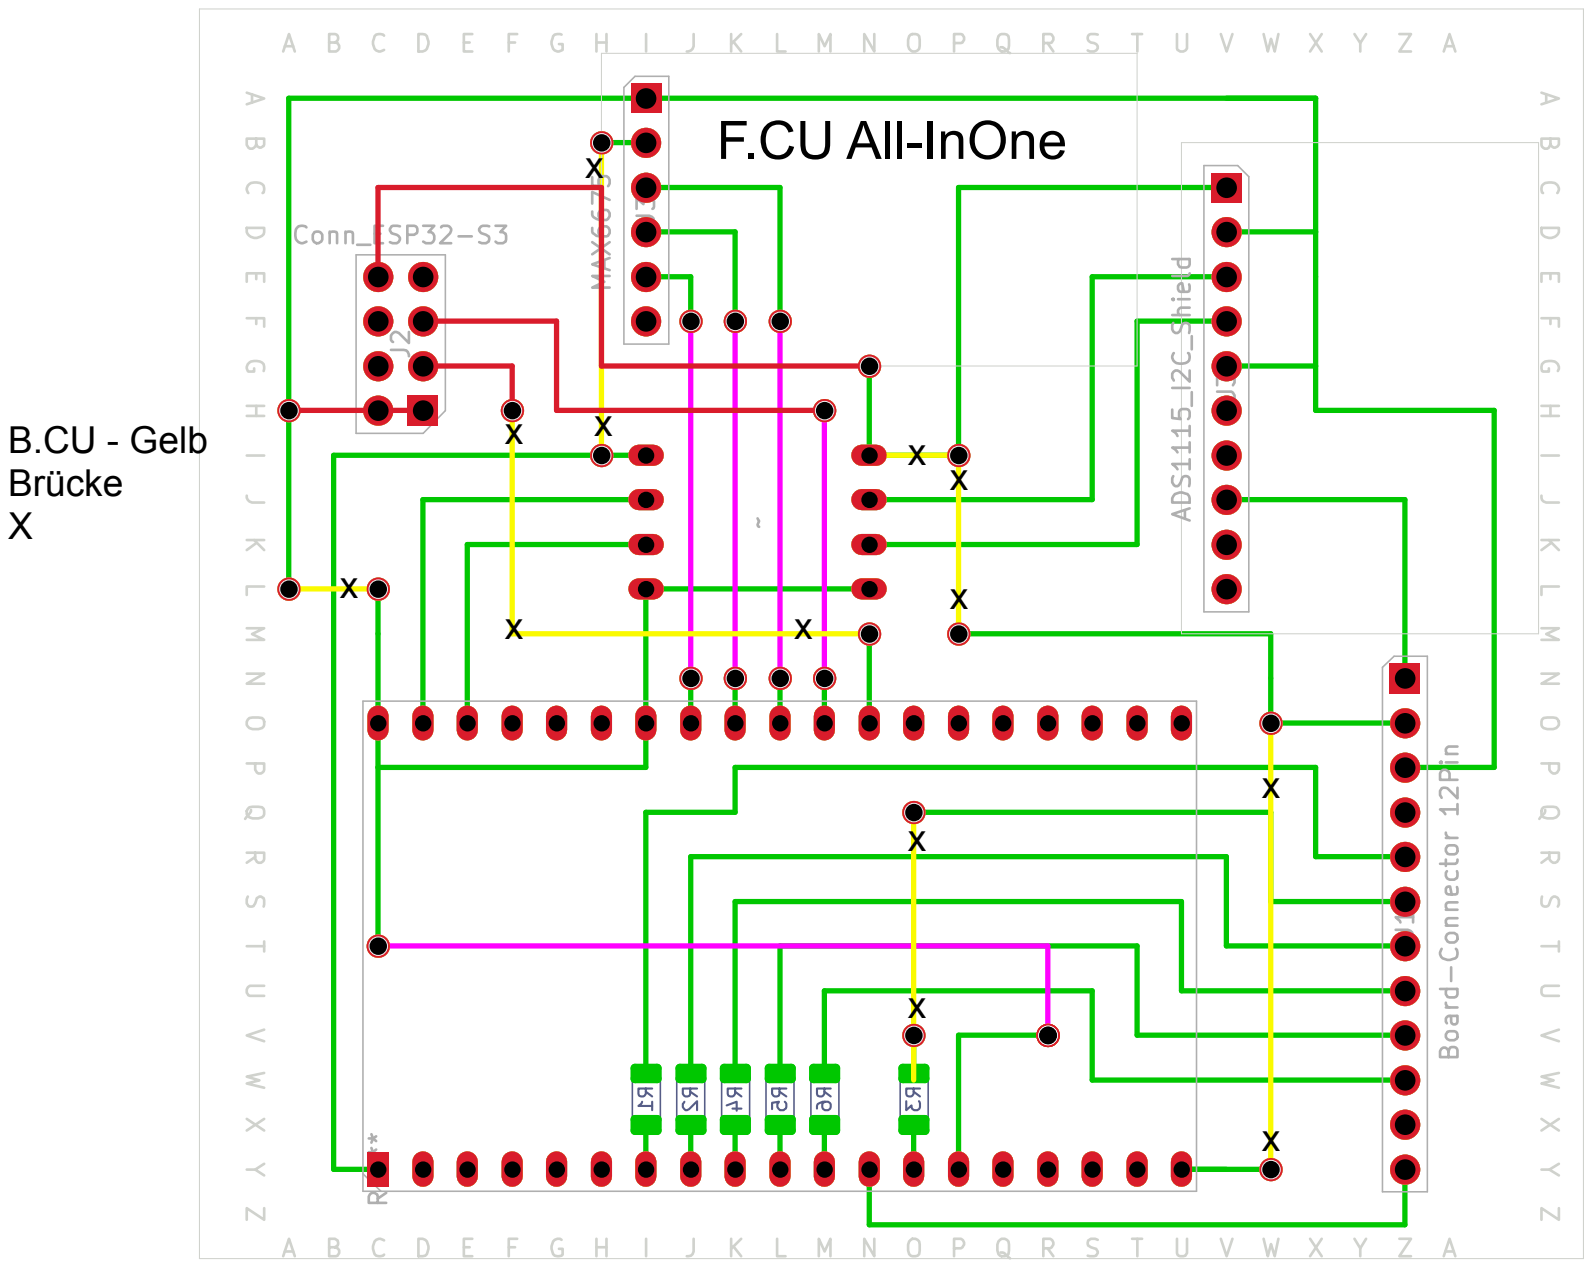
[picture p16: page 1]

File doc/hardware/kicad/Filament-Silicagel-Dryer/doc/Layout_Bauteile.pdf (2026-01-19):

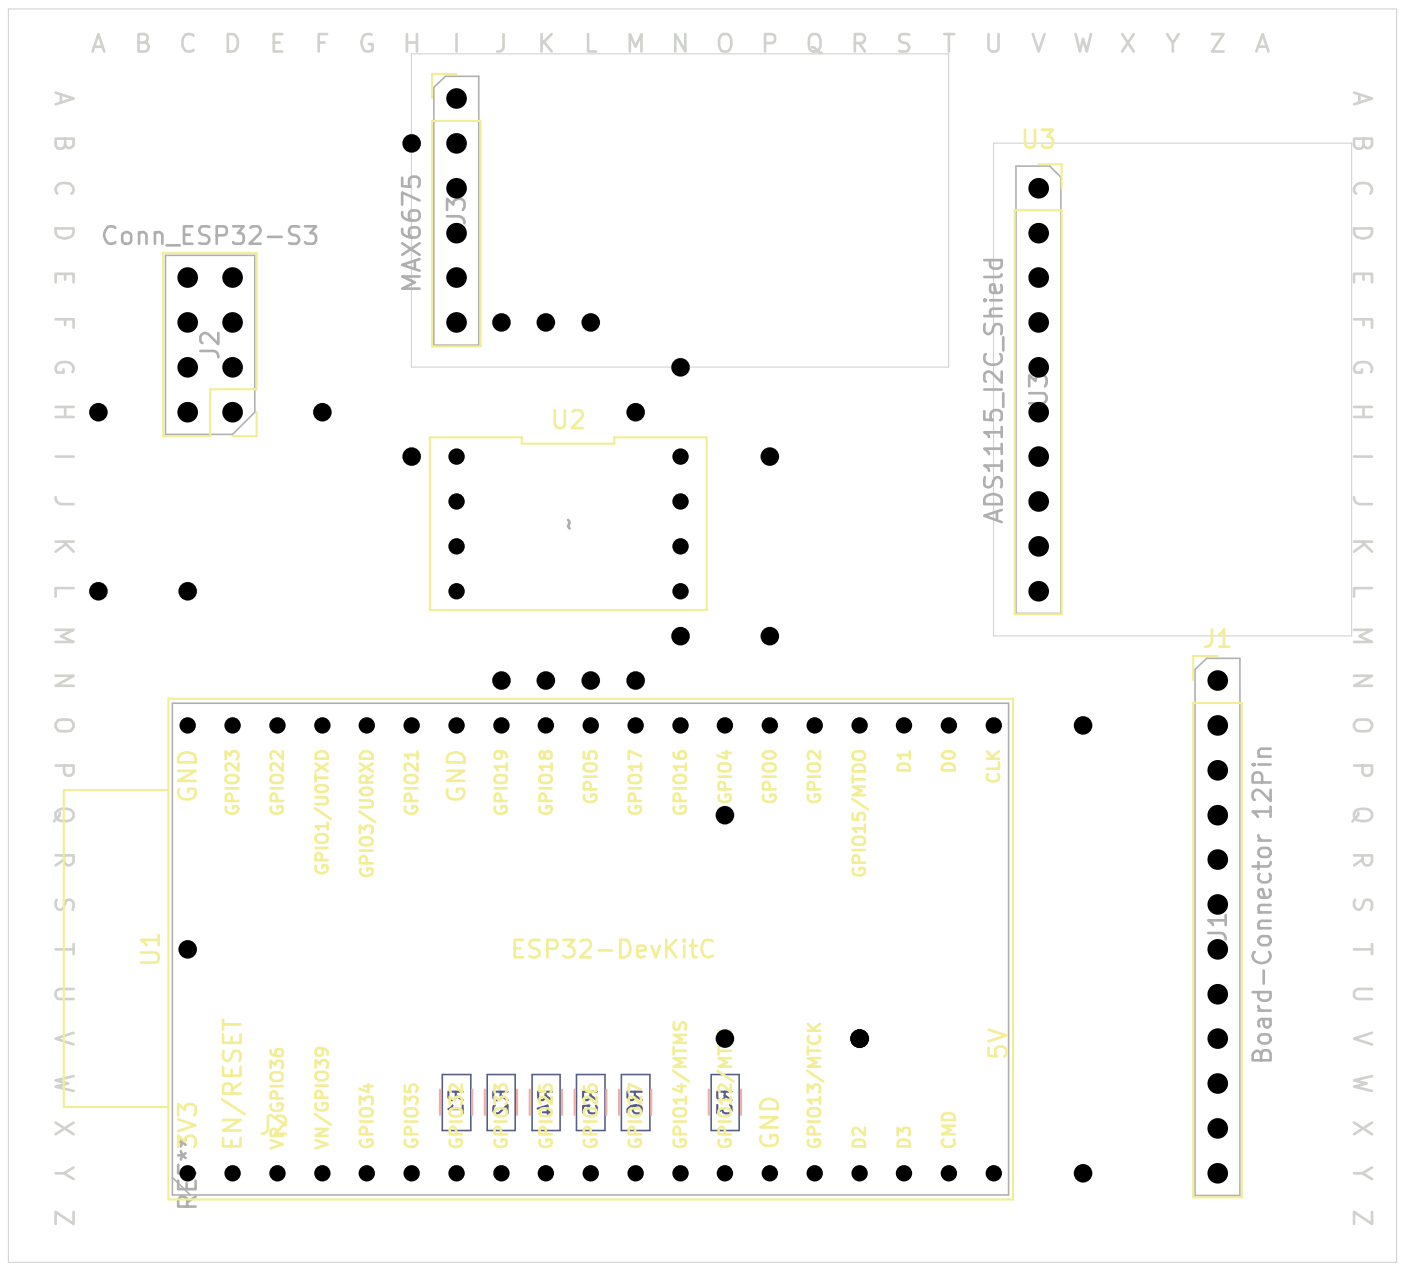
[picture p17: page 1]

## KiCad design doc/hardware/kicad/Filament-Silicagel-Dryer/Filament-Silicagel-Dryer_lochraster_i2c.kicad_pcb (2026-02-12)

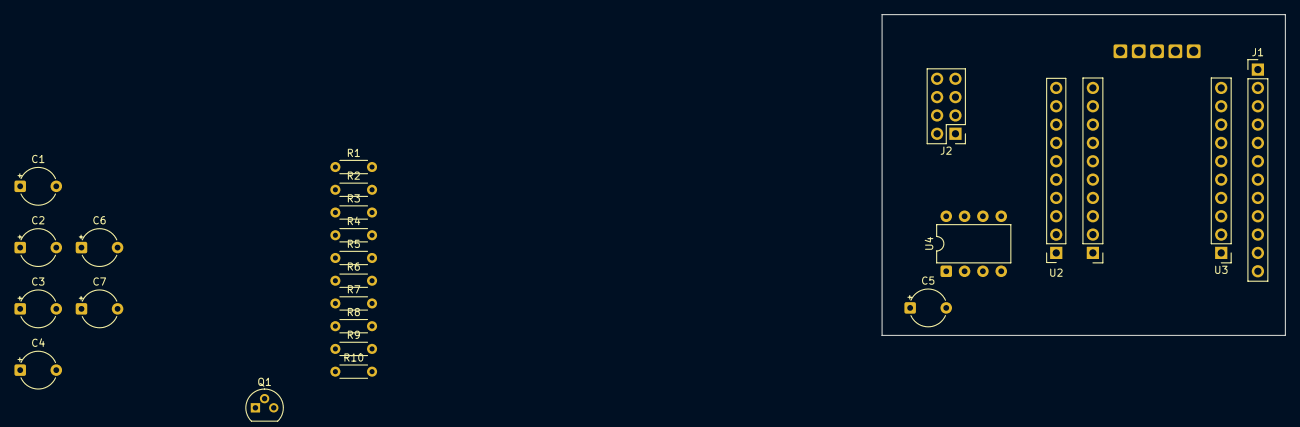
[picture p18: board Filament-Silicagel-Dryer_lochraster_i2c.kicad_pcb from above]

Board: 2 copper layers, 55.9 x 44.4 mm, 23 parts (0 on the bottom side), 22 nets, no tracks yet.

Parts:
C1, C2: 10nF; CP_Radial_Tantal_D5.0mm_P5.00mm
C3, C5, C6, C7: 100nF; CP_Radial_Tantal_D5.0mm_P5.00mm
C4: 10uF; CP_Radial_Tantal_D5.0mm_P5.00mm
J1: Board-Connector 12Pin; PinHeader_1x12_P2.54mm_Vertical
J2: Conn_ESP32-S3; PinHeader_2x04_P2.54mm_Vertical
Q1: BC817; TO-92
R1: 1k; R_Axial_DIN0204_L3.6mm_D1.6mm_P5.08mm_Horizontal
R2, R9: 22k; R_Axial_DIN0204_L3.6mm_D1.6mm_P5.08mm_Horizontal
R3: 10k; R_Axial_DIN0204_L3.6mm_D1.6mm_P5.08mm_Horizontal
R4, R5, R6, R7: 4.7k; R_Axial_DIN0204_L3.6mm_D1.6mm_P5.08mm_Horizontal
R8: 150-220Ohm; R_Axial_DIN0204_L3.6mm_D1.6mm_P5.08mm_Horizontal
R10: 100k; R_Axial_DIN0204_L3.6mm_D1.6mm_P5.08mm_Horizontal
U2: PinSocket_1x10_P2.54mm_Vertical
U3: PCF8575 BreakoutBoard; Connector_PCF8574_BreakOut
U4: ICM7555; DIP-8_W7.62mm

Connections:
3.3V: R4.1, R5.1
5V: C3.1, C4.1, C5.1, C6.2, J1.2, J2.8, R1.1, R3.1, R6.1, R7.1, U2.1 (VDD), U4.8 (VCC)
DOOR: J1.12, U3.19 (P06)
FAN12V: J1.5, R9.1, R10.2, U3.13 (P00), U3.14 (P01)
FAN230V: J1.7, U3.15 (P02)
FAN230V_SLOW: J1.10, U3.16 (P03)
GND: C1.2, C2.1, C3.2, C4.2, C5.2, C6.1, C7.2, J1.3, J2.1, J2.2, Q1.2 (E), R10.1, U2.2 (GND), U3.10 (GND), U3.11 (GND), U4.1 (GND)
HEATER: J1.6, R8.2
LAMP230V: J1.8, U3.18 (P05)
MOTOR230V: J1.9, U3.17 (P04)
NC: J1.4, J1.11
NTC: J1.1, U2.7 (AIN0)
unnamed: Q1.1 (B), R9.2
unnamed: C2.2, U4.5 (CONT)
unnamed: R1.2, R2.1, U4.7 (DISCH)
unnamed: R8.1, U4.3 (OUT)
unnamed: C1.1, R2.2, U4.2 (TRIG), U4.6 (THRES)
RESET: C7.1, Q1.3 (C), R3.2, U4.4 (~RST)
SCA_H: R6.2, U2.3 (SCL)
SCL_L: J2.5, R4.2
SDA_H: R7.2, U2.4 (SDA)
SDA_L: J2.3, R5.2

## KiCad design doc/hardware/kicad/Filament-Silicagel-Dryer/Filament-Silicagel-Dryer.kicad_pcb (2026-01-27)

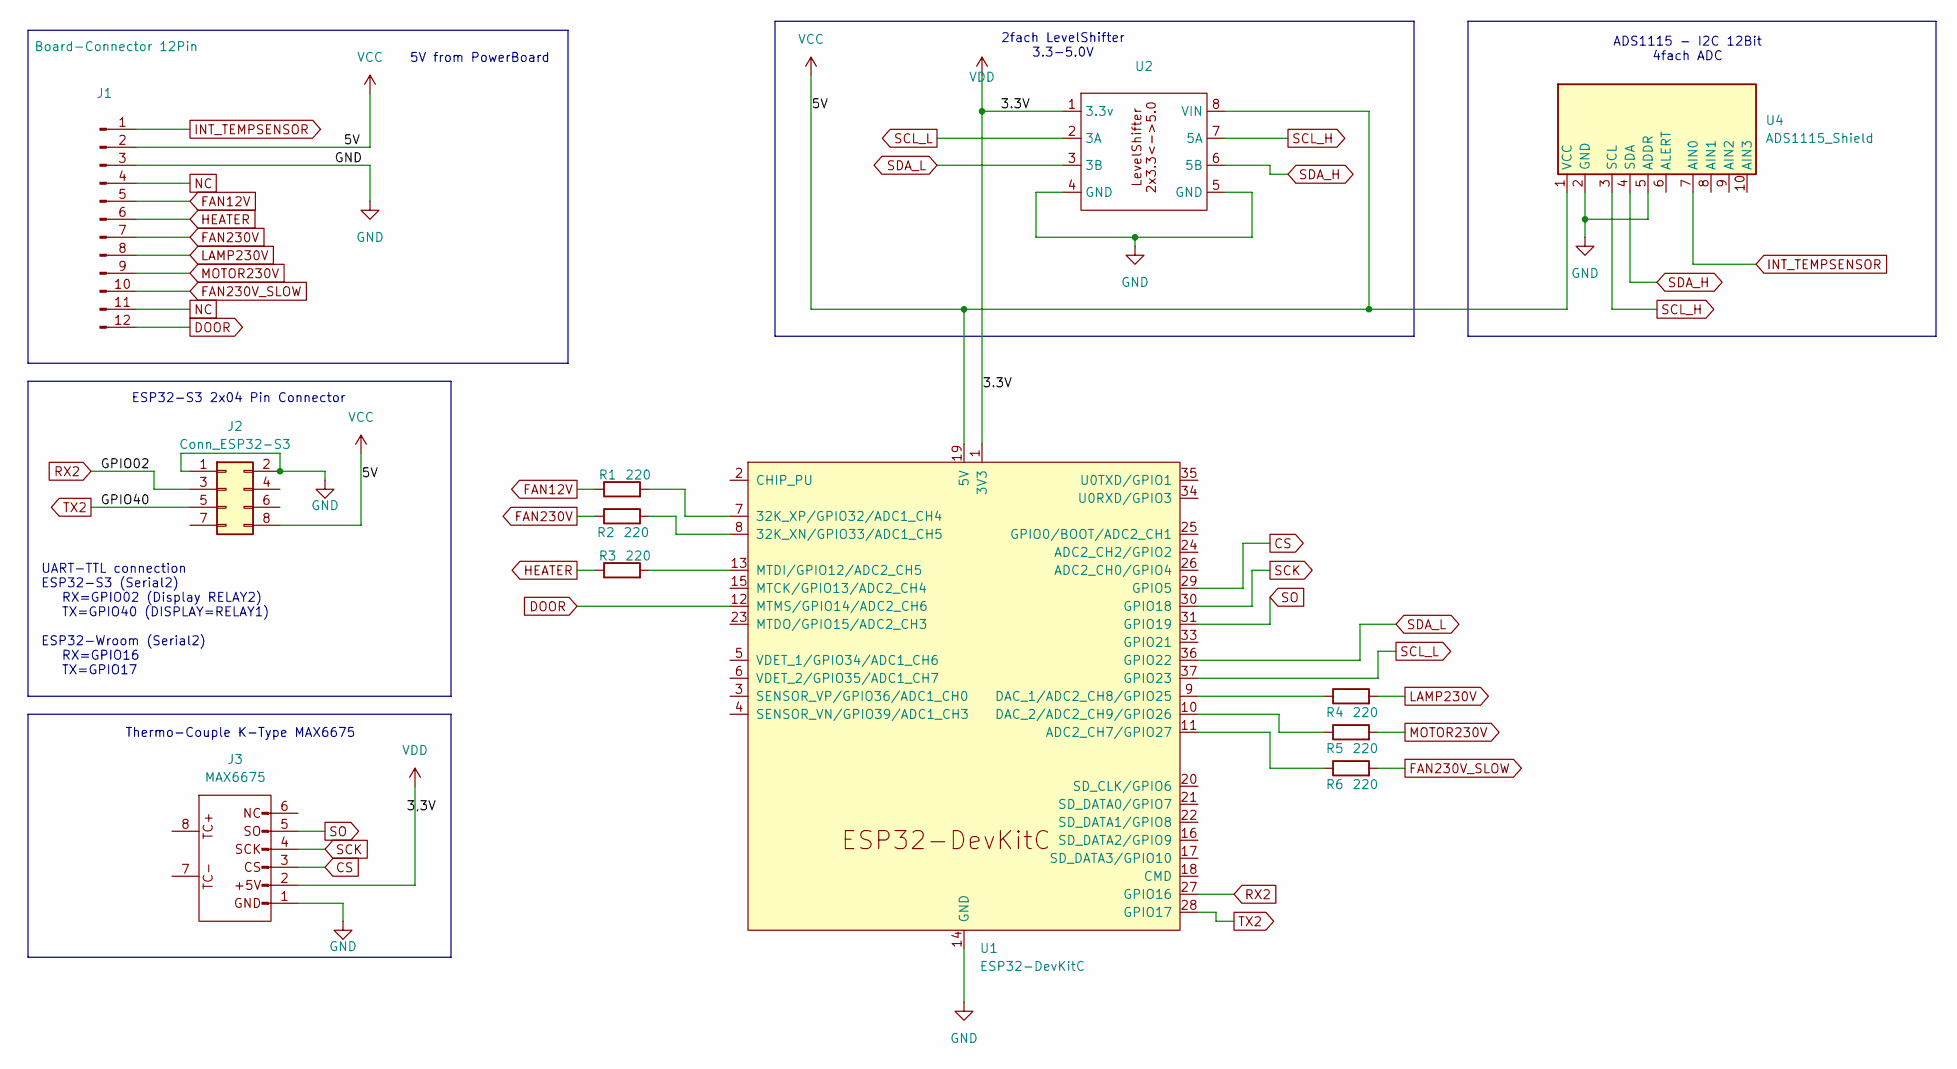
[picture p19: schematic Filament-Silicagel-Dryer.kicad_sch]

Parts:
J1: Board-Connector 12Pin; PinHeader_1x12_P2.54mm_Vertical
J2: Conn_ESP32-S3; PinHeader_2x04_P2.54mm_Vertical
J3: MAX6675; PinHeader_1x06_P2.54mm_Vertical
R1, R2, R3, R4, R5, R6: 220; R_1206_3216Metric
U1: ESP32-DevKitC
U2: LevelShifter_8pin_12.7mm
U4: ADS1115_Shield; PinHeader_1x10_P2.54mm_Vertical

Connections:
CS: J3.3 (CS), U1.29 (GPIO5); also elsewhere on the board
DOOR: J1.12, U1.12 (MTMS/GPIO14/ADC2_CH6)
FAN12V: J1.5, R1.1
FAN230V: J1.7, R2.1
FAN230V_SLOW: J1.10, R6.2
GND: J1.3, J2.1, J2.2, J3.1 (GND), U1.14 (GND), U1.32 (GND), U1.38 (GND), U2.4 (GND), U2.5 (GND), U4.2 (GND), U4.5 (ADDR); also elsewhere on the board
HEATER: J1.6, R3.1
INT_TEMPSENSOR: J1.1, U4.7 (AIN0)
LAMP230V: J1.8, R4.2
MOTOR230V: J1.9, R5.2
NC: J1.4, J1.11
unnamed: R2.2, U1.8 (32K_XN/GPIO33/ADC1_CH5)
unnamed: R1.2, U1.7 (32K_XP/GPIO32/ADC1_CH4)
unnamed: R6.1, U1.11 (ADC2_CH7/GPIO27)
unnamed: R4.1, U1.9 (DAC_1/ADC2_CH8/GPIO25)
unnamed: R5.1, U1.10 (DAC_2/ADC2_CH9/GPIO26)
unnamed: R3.2, U1.13 (MTDI/GPIO12/ADC2_CH5)
RX2: J2.3, U1.27 (GPIO16)
SCK: J3.4 (SCK), U1.30 (GPIO18); also elsewhere on the board
SCL_H: U2.7 (5A), U4.3 (SCL)
SCL_L: U1.37 (GPIO23), U2.2 (3A)
SDA_H: U2.6 (5B), U4.4 (SDA)
SDA_L: U1.36 (GPIO22), U2.3 (3B)
SO: J3.5 (SO), U1.31 (GPIO19); also elsewhere on the board
TX2: J2.5, U1.28 (GPIO17)
VCC: J1.2, J2.8, U1.19 (5V), U2.8 (VIN), U4.1 (VCC)
VDD: J3.2 (+5V), U1.1 (3V3), U2.1 (3.3v); also elsewhere on the board

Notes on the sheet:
UART-TTL connection ESP32-S3 (Serial2) RX=GPIO02 (Display RELAY2) TX=GPIO40 (DISPLAY=RELAY1) ESP32-Wroom (Serial2) RX=GPIO16 TX=GPIO17
Thermo-Couple K-Type MAX6675
ESP32-S3 2x04 Pin Connector
5V from PowerBoard
2fach LevelShifter 3.3-5.0V
ADS1115 - I2C 12Bit 4fach ADC

Board: 2 copper layers, 12 parts (6 on the bottom side), 27 nets, no tracks yet.

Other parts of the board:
J4: MAX6675_5pol; PinSocket_1x05_P2.54mm_Vertical

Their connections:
CS: J4.4 (SCK); also elsewhere on the board
GND: J4.1 (GND); also elsewhere on the board
SCK: J4.3 (CS); also elsewhere on the board
SO: J4.5 (SO); also elsewhere on the board
VDD: J4.2 (+5V); also elsewhere on the board

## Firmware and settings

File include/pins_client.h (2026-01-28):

#pragma once
#include <Arduino.h>

// -------------------------------------------
// Example GPIO pins (REPLACE with real pins)
// -------------------------------------------
constexpr int PIN_CH0 = 32; // GPIO32
constexpr int PIN_CH1 = 33; // GPIO33
constexpr int PIN_CH2 = 25; // GPIO25
constexpr int PIN_CH3 = 26; // GPIO26
constexpr int PIN_CH4 = 27; // GPIO27
constexpr int PIN_CH5 = 14; // GPIO14
constexpr int PIN_CH6 = 12; // GPIO12
constexpr int PIN_CH7 = 13; // GPIO13

constexpr int PIN_CH8 = 04;  // GPIO04
constexpr int PIN_CH9 = 0;   // GPIO0
constexpr int PIN_CH10 = 2;  // GPIO2
constexpr int PIN_CH11 = 15; // GPIO15

// -------------------------------------------
// Analog input pins (FOR CH12–CH15)
// -------------------------------------------
constexpr int PIN_ADC0 = 36; // ADC0
constexpr int PIN_ADC1 = 39; // ADC3
constexpr int PIN_ADC2 = 34; // ADC6
constexpr int PIN_ADC3 = 35; // ADC7

// -------------------------------------------
// MAX6675 thermocouple pins (example)
// -------------------------------------------
constexpr int PIN_MAX6675_SCK = 18; // GPIO18 (SPI_SCK)
constexpr int PIN_MAX6675_CS = 5;   // GPIO5 (SPI_SS)
constexpr int PIN_MAX6675_SO = 19;  // GPIO19 (SPI(MISO))

// -------------------------------------------
// Internel Board-LED
// -------------------------------------------
constexpr int PIN_BOARD_LED = 2;

// -------------------------------------------
// HOST-Mapping GPIO -> Logische Namen
// -------------------------------------------
constexpr int OVEN_FAN12V = PIN_CH0;
constexpr int OVEN_FAN230V = PIN_CH1;
constexpr int OVEN_FAN230V_SLOW = PIN_CH4;
constexpr int OVEN_LAMP = PIN_CH2;
constexpr int OVEN_SILICAT_MOTOR = PIN_CH3;
constexpr int OVEN_DOOR_SENSOR = PIN_CH5;
constexpr int OVEN_HEATER = PIN_CH6;

// ADC-Input
constexpr int OVEN_TEMP1_PORT1 = PIN_ADC0;
constexpr int OVEN_TEMP_KTYPE = PIN_ADC1;

// IMPORTANT: You stated that it must be initialized with RX2/TX2 routing, otherwise it won't work.
constexpr uint8_t CLIENT_RX2 = 16; // GPIO16 = RX2
constexpr uint8_t CLIENT_TX2 = 17; // GPIO17 = TX2

// EOF

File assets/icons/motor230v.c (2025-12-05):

#ifdef __has_include
    #if __has_include("lvgl.h")
        #ifndef LV_LVGL_H_INCLUDE_SIMPLE
            #define LV_LVGL_H_INCLUDE_SIMPLE
        #endif
    #endif
#endif

#if defined(LV_LVGL_H_INCLUDE_SIMPLE)
    #include "lvgl.h"
#else
    #include "lvgl/lvgl.h"
#endif


#ifndef LV_ATTRIBUTE_MEM_ALIGN
#define LV_ATTRIBUTE_MEM_ALIGN
#endif

#ifndef LV_ATTRIBUTE_IMAGE_MOTOR230V
#define LV_ATTRIBUTE_IMAGE_MOTOR230V
#endif

const LV_ATTRIBUTE_MEM_ALIGN LV_ATTRIBUTE_LARGE_CONST LV_ATTRIBUTE_IMAGE_MOTOR230V uint8_t motor230v_map[] = {
  0x00, 0x00, 0x00, 0x00, 0x00, 0x00, 0x00, 0x00, 0x00, 0x00, 0x00, 0x00, 0x00, 0x00, 0x00, 0x00, 0x00, 0x00, 0x00, 0x00, 0x00, 0x00, 0x00, 0x00, 0x00, 0x00, 0x00, 0x00, 0x00, 0x00, 0x00, 0x00, 0x00, 0x00, 0x00, 0x00, 0x00, 0x00, 0x00, 0x00, 0x00, 0x00, 0x00, 0x00, 0x00, 0x00, 0x00, 0x00, 0x00, 0x00, 0x00, 0x00, 0x00, 0x00, 0x00, 0x00, 0x00, 0x00, 0x00, 0x00, 0x00, 0x00, 0x00, 0x00, 0xff, 0xff, 0xff, 0x01, 0xff, 0xff, 0xff, 0x01, 0xff, 0xff, 0xff, 0x01, 0xff, 0xff, 0xff, 0x01, 0xff, 0xff, 0xff, 0x01, 0xff, 0xff, 0xff, 0x01, 0xff, 0xff, 0xff, 0x01, 0x00, 0x00, 0x00, 0x00, 0x00, 0x00, 0x00, 0x00, 0x00, 0x00, 0x00, 0x00, 0x00, 0x00, 0x00, 0x00, 0x00, 0x00, 0x00, 0x00, 0x00, 0x00, 0x00, 0x00, 0x00, 0x00, 0x00, 0x00, 0x00, 0x00, 0x00, 0x00, 0x00, 0x00, 0x00, 0x00, 
  0x00, 0x00, 0x00, 0x00, 0x00, 0x00, 0x00, 0x00, 0x00, 0x00, 0x00, 0x00, 0x00, 0x00, 0x00, 0x00, 0x00, 0x00, 0x00, 0x00, 0x00, 0x00, 0x00, 0x00, 0x00, 0x00, 0x00, 0x00, 0x00, 0x00, 0x00, 0x00, 0x00, 0x00, 0x00, 0x00, 0x00, 0x00, 0x00, 0x00, 0x00, 0x00, 0x00, 0x00, 0x00, 0x00, 0x00, 0x00, 0x00, 0x00, 0x00, 0x00, 0x00, 0x00, 0x00, 0x00, 0x00, 0x00, 0x00, 0x00, 0xff, 0xff, 0xff, 0x01, 0x00, 0x00, 0x00, 0x00, 0x00, 0x00, 0x00, 0x00, 0x00, 0x00, 0x00, 0x00, 0x00, 0x00, 0x00, 0x00, 0x00, 0x00, 0x00, 0x00, 0x00, 0x00, 0x00, 0x00, 0x00, 0x00, 0x00, 0x00, 0xff, 0xff, 0xff, 0x01, 0x00, 0x00, 0x00, 0x00, 0x00, 0x00, 0x00, 0x00, 0x00, 0x00, 0x00, 0x00, 0x00, 0x00, 0x00, 0x00, 0x00, 0x00, 0x00, 0x00, 0x00, 0x00, 0x00, 0x00, 0x00, 0x00, 0x00, 0x00, 0x00, 0x00, 0x00, 0x00, 
  0x00, 0x00, 0x00, 0x00, 0x00, 0x00, 0x00, 0x00, 0x00, 0x00, 0x00, 0x00, 0x00, 0x00, 0x00, 0x00, 0x00, 0x00, 0x00, 0x00, 0x00, 0x00, 0x00, 0x00, 0x00, 0x00, 0x00, 0x00, 0x00, 0x00, 0x00, 0x00, 0x00, 0x00, 0x00, 0x00, 0x00, 0x00, 0x00, 0x00, 0x00, 0x00, 0x00, 0x00, 0x00, 0x00, 0x00, 0x00, 0x00, 0x00, 0x00, 0x00, 0x00, 0x00, 0x00, 0x00, 0xff, 0xff, 0xff, 0x01, 0x00, 0x00, 0x00, 0x00, 0xff, 0xff, 0xff, 0x02, 0xff, 0xff, 0xff, 0x13, 0xff, 0xff, 0xff, 0x0e, 0xff, 0xff, 0xff, 0x0f, 0xff, 0xff, 0xff, 0x0f, 0xff, 0xff, 0xff, 0x10, 0xff, 0xff, 0xff, 0x0e, 0x00, 0x00, 0x00, 0x00, 0x00, 0x00, 0x00, 0x00, 0x00, 0x00, 0x00, 0x00, 0x00, 0x00, 0x00, 0x00, 0x00, 0x00, 0x00, 0x00, 0x00, 0x00, 0x00, 0x00, 0x00, 0x00, 0x00, 0x00, 0x00, 0x00, 0x00, 0x00, 0x00, 0x00, 0x00, 0x00, 
  0x00, 0x00, 0x00, 0x00, 0x00, 0x00, 0x00, 0x00, 0x00, 0x00, 0x00, 0x00, 0x00, 0x00, 0x00, 0x00, 0x00, 0x00, 0x00, 0x00, 0x00, 0x00, 0x00, 0x00, 0x00, 0x00, 0x00, 0x00, 0x00, 0x00, 0x00, 0x00, 0x00, 0x00, 0x00, 0x00, 0x00, 0x00, 0x00, 0x00, 0x00, 0x00, 0x00, 0x00, 0x00, 0x00, 0x00, 0x00, 0x00, 0x00, 0x00, 0x00, 0xff, 0xff, 0xff, 0x01, 0x00, 0x00, 0x00, 0x00, 0xff, 0xff, 0xff, 0x02, 0xff, 0xff, 0xff, 0xbe, 0xff, 0xff, 0xff, 0xf8, 0xff, 0xff, 0xff, 0xf4, 0xff, 0xff, 0xff, 0xf6, 0xff, 0xff, 0xff, 0xf7, 0xff, 0xff, 0xff, 0xf1, 0xff, 0xff, 0xff, 0xf9, 0xff, 0xff, 0xff, 0x62, 0x00, 0x00, 0x00, 0x00, 0xff, 0xff, 0xff, 0x04, 0x00, 0x00, 0x00, 0x00, 0x00, 0x00, 0x00, 0x00, 0x00, 0x00, 0x00, 0x00, 0x00, 0x00, 0x00, 0x00, 0x00, 0x00, 0x00, 0x00, 0x00, 0x00, 0x00, 0x00, 
  0x00, 0x00, 0x00, 0x00, 0x00, 0x00, 0x00, 0x00, 0x00, 0x00, 0x00, 0x00, 0x00, 0x00, 0x00, 0x00, 0x00, 0x00, 0x00, 0x00, 0x00, 0x00, 0x00, 0x00, 0x00, 0x00, 0x00, 0x00, 0x00, 0x00, 0x00, 0x00, 0x00, 0x00, 0x00, 0x00, 0x00, 0x00, 0x00, 0x00, 0x00, 0x00, 0x00, 0x00, 0x00, 0x00, 0x00, 0x00, 0x00, 0x00, 0x00, 0x00, 0xff, 0xff, 0xff, 0x01, 0x00, 0x00, 0x00, 0x00, 0xff, 0xff, 0xff, 0x13, 0xff, 0xff, 0xff, 0xf8, 0xff, 0xff, 0xff, 0xff, 0xff, 0xff, 0xff, 0xdc, 0xff, 0xff, 0xff, 0xdd, 0xff, 0xff, 0xff, 0xdb, 0xff, 0xff, 0xff, 0xe4, 0xff, 0xff, 0xff, 0xff, 0xff, 0xff, 0xff, 0x98, 0x00, 0x00, 0x00, 0x00, 0xff, 0xff, 0xff, 0x05, 0x00, 0x00, 0x00, 0x00, 0x00, 0x00, 0x00, 0x00, 0x00, 0x00, 0x00, 0x00, 0x00, 0x00, 0x00, 0x00, 0x00, 0x00, 0x00, 0x00, 0x00, 0x00, 0x00, 0x00, 
  0x00, 0x00, 0x00, 0x00, 0x00, 0x00, 0x00, 0x00, 0xff, 0xff, 0xff, 0x01, 0xff, 0xff, 0xff, 0x03, 0xff, 0xff, 0xff, 0x03, 0xff, 0xff, 0xff, 0x03, 0xff, 0xff, 0xff, 0x03, 0xff, 0xff, 0xff, 0x03, 0xff, 0xff, 0xff, 0x03, 0xff, 0xff, 0xff, 0x03, 0xff, 0xff, 0xff, 0x03, 0xff, 0xff, 0xff, 0x03, 0xff, 0xff, 0xff, 0x03, 0xff, 0xff, 0xff, 0x04, 0x00, 0x00, 0x00, 0x00, 0xff, 0xff, 0xff, 0x12, 0xff, 0xff, 0xff, 0xf5, 0xff, 0xff, 0xff, 0xdb, 0xff, 0xff, 0xff, 0x01, 0xff, 0xff, 0xff, 0x06, 0x00, 0x00, 0x00, 0x00, 0xff, 0xff, 0xff, 0x4c, 0xff, 0xff, 0xff, 0xff, 0xff, 0xff, 0xff, 0x8d, 0x00, 0x00, 0x00, 0x00, 0xff, 0xff, 0xff, 0x04, 0x00, 0x00, 0x00, 0x00, 0x00, 0x00, 0x00, 0x00, 0x00, 0x00, 0x00, 0x00, 0x00, 0x00, 0x00, 0x00, 0x00, 0x00, 0x00, 0x00, 0x00, 0x00, 0x00, 0x00, 
  0x00, 0x00, 0x00, 0x00, 0xff, 0xff, 0xff, 0x04, 0x00, 0x00, 0x00, 0x00, 0x00, 0x00, 0x00, 0x00, 0x00, 0x00, 0x00, 0x00, 0x00, 0x00, 0x00, 0x00, 0x00, 0x00, 0x00, 0x00, 0x00, 0x00, 0x00, 0x00, 0x00, 0x00, 0x00, 0x00, 0x00, 0x00, 0x00, 0x00, 0x00, 0x00, 0x00, 0x00, 0x00, 0x00, 0x00, 0x00, 0x00, 0x00, 0x00, 0x00, 0x00, 0x00, 0x00, 0x00, 0x00, 0x00, 0x00, 0x00, 0xff, 0xff, 0xff, 0x04, 0xff, 0xff, 0xff, 0xf7, 0xff, 0xff, 0xff, 0xd9, 0x00, 0x00, 0x00, 0x00, 0x00, 0x00, 0x00, 0x00, 0x00, 0x00, 0x00, 0x00, 0xff, 0xff, 0xff, 0x41, 0xff, 0xff, 0xff, 0xff, 0xff, 0xff, 0xff, 0x88, 0x00, 0x00, 0x00, 0x00, 0xff, 0xff, 0xff, 0x07, 0xff, 0xff, 0xff, 0x02, 0x00, 0x00, 0x00, 0x00, 0x00, 0x00, 0x00, 0x00, 0x00, 0x00, 0x00, 0x00, 0x00, 0x00, 0x00, 0x00, 0x00, 0x00, 0x00, 0x00, 
  0xff, 0xff, 0xff, 0x02, 0x00, 0x00, 0x00, 0x00, 0xff, 0xff, 0xff, 0x0a, 0xff, 0xff, 0xff, 0x33, 0xff, 0xff, 0xff, 0x37, 0xff, 0xff, 0xff, 0x36, 0xff, 0xff, 0xff, 0x36, 0xff, 0xff, 0xff, 0x36, 0xff, 0xff, 0xff, 0x38, 0xff, 0xff, 0xff, 0x3b, 0xff, 0xff, 0xff, 0x38, 0xff, 0xff, 0xff, 0x36, 0xff, 0xff, 0xff, 0x36, 0xff, 0xff, 0xff, 0x37, 0xff, 0xff, 0xff, 0x33, 0xff, 0xff, 0xff, 0x42, 0xff, 0xff, 0xff, 0xf5, 0xff, 0xff, 0xff, 0xdf, 0xff, 0xff, 0xff, 0x36, 0xff, 0xff, 0xff, 0x3a, 0xff, 0xff, 0xff, 0x2b, 0xff, 0xff, 0xff, 0x71, 0xff, 0xff, 0xff, 0xff, 0xff, 0xff, 0xff, 0xa6, 0xff, 0xff, 0xff, 0x10, 0x00, 0x00, 0x00, 0x00, 0x00, 0x00, 0x00, 0x00, 0xff, 0xff, 0xff, 0x03, 0x00, 0x00, 0x00, 0x00, 0x00, 0x00, 0x00, 0x00, 0x00, 0x00, 0x00, 0x00, 0x00, 0x00, 0x00, 0x00,
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

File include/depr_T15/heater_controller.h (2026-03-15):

#pragma once
#include <stdint.h>

namespace hcc {

// Temperature unit: deci-degrees Celsius (dC). Example: 40.0°C -> 400 dC.
static constexpr int16_t TEMP_INVALID_DC = (int16_t)-32768;

enum class HeaterMode : uint8_t {
    SAFE_OFF = 0, // Door open or safety trip => always off
    HEAT_UP,      // Aggressive heat until we approach target
    APPROACH,     // Reduced energy close to target (avoid overshoot)
    HOLD          // Maintain in-band using windowed duty
};

struct HeaterControllerConfig {
    // Target band
    int16_t target_dC = 400;        // 40.0°C
    int16_t maxOvershoot_dC = 50;   // +5.0°C
    int16_t minUndershoot_dC = 100; // -10.0°C

    // Safety caps (controller-level, not a replacement for SafetyGuard/T14)
    int16_t abortTemp_dC = 1200; // 120.0°C hard cutoff

    // Hotspot-based soft cap to prevent early overshoot:
    // If hotspot rises too far above chamber, reduce/stop heating.
    int16_t hotspotDeltaMax_dC = 150; // +15.0°C above chamber
    int16_t hotspotAbsMax_dC = 1150;  // 115.0°C absolute cap (soft)

    // Prediction / smoothing
    // Chamber slope is low-pass filtered. This tau models "thermal lag" of chamber response.
    uint16_t slopeLpfAlpha_256 = 32; // 0..256 (higher = faster), 32 ~= 0.125
    uint16_t predictTau_s = 12;      // seconds of "expected remaining rise" after turning off

    // Hold windowing (simple, robust)
    uint16_t holdWindowMs = 2000; // 2s windows
    uint8_t minDutyHoldPct = 0;   // clamp lower bound
    uint8_t maxDutyHoldPct = 70;  // clamp upper bound in HOLD
};

struct HeaterControllerInput {
    uint32_t nowMs = 0;

    bool doorClosed = true;

    int16_t chamber_dC = TEMP_INVALID_DC;
    int16_t hotspot_dC = TEMP_INVALID_DC;
};

struct HeaterControllerOutput {
    HeaterMode mode = HeaterMode::SAFE_OFF;

    // Requested heater energy in percent (0..100).
    // The caller decides whether this maps to PWM duty or "window ON time".
    uint8_t dutyPercent = 0;

    // Diagnostics for UDP logs
    int16_t chamberSlope_dC_per_s = 0; // filtered slope
    int16_t predictedChamber_dC = TEMP_INVALID_DC;
    uint8_t reasons = 0; // bitfield (see ReasonBits)
};

struct HeaterControllerState {
    HeaterMode mode = HeaterMode::SAFE_OFF;

    // Slope estimation
    int16_t lastChamber_dC = TEMP_INVALID_DC;
    uint32_t lastChamberMs = 0;
    int32_t slopeFilt_dC_per_s = 0; // internal (scaled int)

    // HOLD window scheduler
    uint32_t windowStartMs = 0;
    uint16_t windowOnMs = 0;
};

// Reason bits (for output.reasons)
struct ReasonBits {
    static constexpr uint8_t DOOR_OPEN = 1u << 0;
    static constexpr uint8_t INVALID_SENSOR = 1u << 1;
    static constexpr uint8_t ABORT_TEMP = 1u << 2;
    static constexpr uint8_t HOTSPOT_CAP = 1u << 3;
    static constexpr uint8_t PREDICT_CUTOFF = 1u << 4;
    static constexpr uint8_t IN_BAND = 1u << 5;
};

class HeaterController {
  public:
    explicit HeaterController(const HeaterControllerConfig &cfg);

    void reset(uint32_t nowMs);
    HeaterControllerOutput update(const HeaterControllerInput &in);

    const HeaterControllerConfig &config() const { return cfg_; }
    const HeaterControllerState &state() const { return st_; }

  private:
    HeaterControllerConfig cfg_;
    HeaterControllerState st_;

    bool sensorsValid_(const HeaterControllerInput &in) const;

    void updateSlope_(const HeaterControllerInput &in);
    int16_t predictedChamber_(int16_t chamber_dC, int16_t slope_dC_per_s) const;

    // mode handlers
    HeaterControllerOutput runSafe_(const HeaterControllerInput &in, uint8_t reasons);
    HeaterControllerOutput runHeatUp_(const HeaterControllerInput &in);
    HeaterControllerOutput runApproach_(const HeaterControllerInput &in, int16_t slope_dC_per_s, int16_t pred_dC);
    HeaterControllerOutput runHold_(const HeaterControllerInput &in, int16_t slope_dC_per_s, int16_t pred_dC);

    // duty helper
    uint8_t clampDuty_(int32_t dutyPct, uint8_t minPct, uint8_t maxPct) const;

    // window scheduling for HOLD
    uint8_t dutyHoldToWindowPct_(int16_t err_dC) const;
    bool windowShouldBeOn_(uint32_t nowMs) const;
};

} // namespace hcc

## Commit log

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2025-12-06 src-folder struct auf src/app und src/test angepasst. platformio.ini erweitert für src/test/i2c test und weitere tests-module. Compiliert und flash. Darstelleung in ordnung ohne Zeiger. ButtonEvent o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
2025-12-06 src-folder struct auf src/app und src/test angepasst. platformio.ini erweitert für src/test/i2c test und weitere tests-module. Compiliert und flash. Darstelleung in ordnung ohne Zeiger. ButtonEvent o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
2025-12-16 T4: Zeit läuft rückwärts, Progressbar läuft, zweiten Button (PAUSE) hinzugefügt, volle funktionalität aber noch nicht implementiert.
2025-12-16 T4 - UI: introduce RUNNING/WAIT state machine, pause handling and door safety logic
    - Added explicit RunState (STOPPED/RUNNING/WAIT) to main screen logic
    - Implemented WAIT behavior with manual resume after door close
    - Countdown timer now pauses immediately on door open
    - Pause/WAIT button enablement tied to door state (safety-first)
    - Door state simulation added for UI testing without hardware
    - Unified countdown, needle and progress bar behavior
    - Improved UI feedback: START/STOP/WAIT states, button labeling and colors
    - Fixed race conditions between UI countdown and oven runtime updates
2025-12-16 T4 - bugfix from last commit UI: implement WAIT/Pause state with safety handling and consistent countdown control
    - Introduced explicit RunState state machine (STOPPED / RUNNING / WAIT)
    - Added PAUSE/WAIT button with proper enable/disable and color feedback
    - Implemented WAIT mode:
    - Countdown timer is stopped
    - Remaining time is preserved
    - Actuator states are snapshotted and restored on resume
    - Enforced safety behavior on door open:
    - Immediate transition to WAIT
    - Heater and motor forced OFF
    - Fans and lamp set to safe state
    - Fixed icon state handling when resuming from WAIT
    - Unified countdown ownership to avoid UI/runtime flicker
    - Improved logging and debug visibility for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
    [oven.cpp, oven.h]
2025-12-17 - Ersetzt Linien-/Blockmarker der Temperaturanzeige durch PNG-Dreiecke für IST- und SOLL-Temperatur - Farblogik für CURRENT-Temperatur: - Blau: unter Zielbereich - Grün: innerhalb Zielbereich (± Tole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
2025-12-19 - Zentrale Preset-Anzeige im Dial als abgerundetes Rechteck umgesetzt - Anzeige von Preset-Name und Filament-ID (#ID) im Hauptscreen - Visuelle Gewichtung bewusst dezent gehalten (Opacity, Größe, Far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
    Ziel: Auf einen Blick erkennbare Key-Facts (Preset, Zeit, Temperatur)
    ohne visuelle Überladung oder komplexe Layout-Logik.
2025-12-20 swipe über alle drei Screen implementiert. screen_config und screen_log sind aber leer
2025-12-21 T5.3.3 implementiert screen_config: Buttons inkl. Callback verfügbar. SAVE/CLEAR implementiert. Im RUN-Mode ist der screen_config nicht verfügbar
2025-12-22 grundlegende Funktionalität für screen_config inkl. Layout fertig.
    layout hat noch kleinere Fehler.
    Noch keine Test des Workflows selber, Filament-Change wechselt auch HH:MM und TEMP zu den entsprechenden werten
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2025-12-27 nightly 20251227 (Update der Needles nach screen_config funktioniert noch nicht - alter codestand commited)
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2026-01-07 TC12-TC16 implementiert und erfolgreich ausgeführt.
    Die Entwicklung von Testscases schließen wir hier:
    BEDENKEN:
    Alle technischen TestCases die tatsächlich Hardware schalten, dürfen nicht im EchtSystem durchgeführt werden. Dies kann zu Schäden führen
2026-01-10 T17 - grundlegende lauffähigkeit zwischen HOST & CLIENT. UI-Updates ok basieren auf oven_runtime_status POST-Phase pro Preset möglich und OK UI-Updates OK
    offen:
    Im PostMode visuelle Darstellung in UI notwendig (zB. statt background GREEN (Filmament) in Blau.
    Dial-Frame von Orange in Blau
    ....
    Umfangreiche Tests noch nicht durchgeführt
2026-01-11 nighly - kleinere Bugs vorhanden. icon SYNC nicht korrekt Fail-Safe-Mode zw. HOST-CLIENT nicht vorhanden Noch nicht alle Tests durchgeführt. Aktueller Stand T7
    [oven.cpp, oven.h]
2026-01-11 T7 AP 3.2 Kurz-Status (mentales Häkchen setzen) • ✅ LinkSync Rising Edge → SAFE STOP funktioniert • ✅ Alive-Timeout → SAFE STOP funktioniert • ✅ Icon wechselt korrekt (rot ↔ grün) • ✅ Log-Ausgaben je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
2026-01-11 T7 AP 3.3 Fix commAlive flicker and stabilize LinkSync handling
    - Add keep-alive PINGs while synced to prevent commAlive timeout flicker
    - Separate linkSynced (handshake) from commAlive (RX freshness)
    - Fix lastRxAny tracking for ACK/STATUS/PONG frames
    - Ensure SAFE STOP is sent once per outage/sync session
    - Correct debug logging (format/argument mismatch)
    [oven.cpp, oven.h]
2026-01-11 T7 AP4.1b: Stabilize link sync / alive handling and UI state reflection
    - Mirror HostComm RX timestamps into OvenRuntimeState
    - Add safe STOP on alive-timeout and on link-sync rising edge
    - Prevent stale actuator coloring by forcing local STOP on comm loss
    - Keep UI link icon driven solely by runtimeState.linkSynced
    - Reduce log noise, keep diagnostics behind compiler flags
    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
    [oven.cpp]
2026-01-11 T7 AP 4.2
    screen_main: POST-Visuals (Preset-Box und Dial-Rahmen blau)
    • UI: POST-Zustand visuell hervorheben (blaues Preset, blauer Dial)
2026-01-11 T7 AP4.3 – POST nutzt identische Aktuator-Iconlogik wie RUNNING • Klarstellung: POST und RUNNING teilen sich bewusst dieselbe Icon-Darstellung • Keine Sonderfarben oder Overrides für POST-Modus • Mod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
2026-01-12 Mit T8 wird ein temporärer Debug-Hardware-Screen (screen_dbg_hw) eingeführt, der gezieltes manuelles Schalten einzelner Hardware-Ports zu Testzwecken erlaubt.
    Der Screen ist strikt vom produktiven Betrieb getrennt und hält die bestehende
    T7-Architektur vollständig ein (Single Source of Truth über oven.cpp).
    Wesentliche Punkte:
    - Neuer screen_dbg_hw mit Icons, Rows, Verbindungslinien und Temperaturanzeige
    - RUN-Gate als UI-Sicherheitsmechanismus (armed / disarmed)
    - Zentrale Safety-Funktion oven_force_outputs_off()
    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
2026-01-19 KiCad PCB/Schaltplan hinzugefügt ESP32-Wroom Client hinzugefügt Dokumentationen erweitert
    [Filament-Silicagel-Dryer.kicad_pcb, Filament-Silicagel-Dryer.kicad_sch, Filament-Silicagel-Dryer_lochraster.kicad_pcb]
2026-01-27 Abschluß T9 Dokumentationen umsortierungen von Dateien ...
    [Filament-Silicagel-Dryer.kicad_pcb, Filament-Silicagel-Dryer_lochraster.kicad_pcb, Filament-Silicagel-Dryer_lochraster.kicad_sch]
2026-01-28 T10.1.35: Fix heater PWM attach handling on client (GPIO12)
    Ensure LEDC attach result is checked before marking heater PWM as running.
    Prevent false PWM-active state and invalid ledcDetach calls.
    Fixes missing 4kHz PWM output on HEATER (GPIO12 / P6).
    [oven.cpp, oven.h, pins_client.h]
2026-01-28 T10.1.36a: Vorbereitung Door-Safety-Gating im Client
    DOOR-Zustand als reinen Sensor behandeln und aus der Output-Maske entkoppeln,
    um clientseitiges Safety-Gating zu ermöglichen.
2026-01-28 T10.1.35: HEATER-PWM Start stabilisiert. Beim Aktivieren des Heaters wird der PWM-Output nun deterministisch „gekickt“ (Duty=0 → kurze Settling-Delay → Duty setzen), damit das 4kHz-Signal zuverlässig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
    Wenn du willst, machen wir als Nächstes T10.1.36b (Door-Safety-Gating inkl. FAN230 OFF bei DOOR OPEN, FAN230_SLOW bleibt any).
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2026-01-29 T10.1.37: Sicherheits- und Übertemperatur-Fixes Host + Client
    Client:
    - Korrekte Abbildung des effektiven OutputsMask entsprechend des realen Hardware-Zustands.
    - DOOR bleibt strikt input-only (reine Telemetrie), wird niemals als Output angesteuert.
    - Autoritative Door-Safety auf dem Client:
    - DOOR OPEN erzwingt sofortiges Abschalten von HEATER, MOTOR und FAN230.
    - PWM-Heater wird hart deaktiviert (ledcDetach), inkl. konsistenter Shadow-Maske.
    - PWM-Start/Stop deterministisch gemacht (Kick + sichere Abschaltung).
    - STATUS spiegelt zuverlässig den tatsächlichen PWM-Zustand wider.
    - Verifiziert mit Oszi: 4 kHz PWM endet zuverlässig bei DOOR OPEN.
    Host:
    - Host-seitige Over-Temperature-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
    [oven.cpp, oven.h]
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2026-01-30 T10.1.39 – UI & Logik Improvements
    Erweiterung der Overtemperature-Behandlung:
    Bei Übertemperatur wird zusätzlich zur Heater-Abschaltung gezielt auf schnelle Kühlung umgeschaltet (FAN230V EIN, FAN230V_SLOW AUS).
    Sobald die Temperatur wieder unter (Target – Tolerance) fällt und der Heater wieder freigegeben wird, wird automatisch auf den Normalbetrieb zurückgeschaltet (FAN230V AUS, FAN230V_SLOW EIN).
    Einführung von TopBar2 im screen_main:
    Vollbreite Status-/Lauftext-Leiste mit abgerundetem Rahmen zwischen TopBar und Center-Bereich.
    Unterstützt zentrierten Text bei kurzen Meldungen sowie Marquee-Lauftext bei längeren Nachrichten.
    Timeout blendet ausschließlich den Text aus, der F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
2026-01-30 T10.1.40: fail-safe client watchdog (HOST timeout -> outputs=0, heater PWM off)
2026-01-30 10.1.41 – Fix: deterministischer PWM-Start des Heaters beim ersten START nach Boot
    Behebt einen kritischen Initialisierungsfehler im Client, bei dem der HEATER beim ersten START nach Systemboot trotz gesetztem OutputsMask kein 4 kHz-PWM-Signal erzeugt hat. Ursache war ein nicht-deterministischer LEDC-Startzustand: der erste ledcAttach + ledcWrite nach Boot führte sporadisch zu keinem aktiven PWM-Signal, obwohl der Codepfad korrekt durchlaufen wurde.
    Der Fehler zeigte sich nur beim ersten START, während STOP → START zuverlässig funktionierte, da hierbei ein expliziter Detach/Attach-Zyklus stattfand.
    Fix:
    • PWM-Enable wurde so angepasst, dass ein deterministischer Start garantiert i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
2026-02-12 T10 abgeschlossen, Docu zum Display (Hersteller) hinzugefügt
    [4.0 inches IO pin distribution.xlsx, Filament-Silicagel-Dryer_lochraster_i2c.kicad_pcb, Filament-Silicagel-Dryer_lochraster_i2c.kicad_sch]
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2026-02-19 T13 Step 4.0: Host integration for dual-NTC architecture<<<
    Host firmware updated to support the new T13 dual-NTC architecture.
    - Removed legacy tempRaw from ProtocolStatus
    - Updated protocol parsing to use tempHotspot_dC and tempChamber_dC
    - Adjusted HostComm logging and status handling
    - Replaced thermal model input with direct chamber temperature
    - runtimeState.tempCurrentC now derived from tempChamber_dC
    - Maintained Single Source of Truth via oven runtime state
    Result:
    Host now operates on physically measured chamber temperature for control,
    while hotspot temperature is available for safety supervision.
    The legacy PT1/bias thermal model is fully removed from the control path.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
    [oven.cpp]
2026-02-19 T13 Step 4.1.0: Add safety layer and relay-safe heater control
    Implemented safety supervision and relay-safe heater control based on the new dual-NTC architecture.
    - Added safetyCutoffActive flag to OvenRuntimeState
    - Implemented hotspot hard cutoff using tempHotspot_dC
    - Implemented chamber fail-safe temperature limit
    - Added overshoot cap protection relative to target temperature
    - Introduced relay-safe timing guards (minimum ON/OFF durations)
    - Ensured heater is forced OFF under safety conditions
    - Preserved Single Source of Truth via oven runtime state
    System now enforces hardware-level safety using physically measured hotspot and chamber temperatures,
    preventing overh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
    [oven.cpp, oven.h]
2026-02-19 BugFix : Drift Screen nach rechts
    [display_hsd040bpn1.cpp]
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2026-02-25 T14.0 client: implement SafetyGuard safe-state and safety latch
    - add enterSafeState_() central fail-safe handler
    - heater forced OFF on parse errors, RX overflow, HostRst, unexpected frames
    - add safety latch: heater remains OFF until explicit SET/UPD/TOG from host
    - refactor host timeout handling to use central safe-state logic
    - ensure deterministic and testable safety behaviour
2026-02-25 T14.0 client: SafetyGuard in handleIncomingLine (parse/unknown/rst -> SAFE)
    - enter SAFE on parse errors and unexpected frame types
    - feed host watchdog only on expected host frames
    - treat HostRst as immediate safe condition
    - keep safety latch until explicit SET/UPD/TOG
    - clean up duplicate flags and improve RX logging
2026-02-26 CLIENT T14.0: implement SafetyGuard with deterministic fail-safe behavior and full unit test coverage
    Introduce client-side SafetyGuard to guarantee that HEATER and other critical outputs
    can only be active while a valid and synchronized host link is present.
    Core SafetyGuard features:
    - Default-safe boot state (outputs forced OFF, safety latch active)
    - Host watchdog with timeout detection (automatic safe-state on link loss)
    - Immediate safe-state on protocol violations:
    - ParseError
    - UnexpectedFrame
    - HostRst
    - RxOverflow
    - Deterministic safety latch behavior:
    - Latch prevents outputs from re-enabling automatically
    - Latch is cleared only by explicit host control frames (SET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
2026-02-27 T15 Step 1: Introduce client_heater_curve test endpoint (Client-only Heater Curve Lab baseline)
    Purpose:
    Establish a minimal, standalone Client endpoint to experimentally evaluate heater control behavior
    without HostComm dependency. This endpoint will serve as a controlled environment to develop and
    validate a stable heater curve algorithm for the chamber temperature (Dual-NTC architecture).
    Key characteristics:
    - New endpoint: src/client/T15/client_heater_curve.cpp
    - No ClientComm, no protocol handling, no Host interaction
    - UDP logging initialized via udp::begin("CLIENT") and log_core.h (INFO/WARN/ERROR/DBG)
    - Door input configured (INPUT_PULLUP), polarity verified:
    DOOR_OPEN = HIGH (5V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
    [FSD_Client.h, heater_controller.h, ntc.h]
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2026-03-15 T15-2.3: stabilize chamber-only test framework and logging before CSV extension
    Current state:
    - Chamber NTC measurement fully functional (ADS1115 CH1)
    - Hotspot channel temporarily disabled but still logged as NaN (Thot=nanC)
    - Heater curve test state-machine working:
    HEATING → RUNOUT → WAIT_FOR_COOL → NEXT RUN
    - Overshoot detection and time-to-peak measurement implemented
    - Door safety handling verified
    - Log output validated with UDP logging
    Additional refactoring:
    - NTC measurement moved into sensors/sensor_ntc.{h,cpp}
    - client_heater_curve file cleaned up
    - include path updated to:
    #include "sensors/sensor_ntc.h"
    Purpose of this checkpoint:
    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
2026-03-27 T16_Phase_1.1 avoid redundant heater SET traffic
    [oven.cpp]
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2026-03-31 T16_Phase_3.5 tighten filament hold reheat
    [oven.cpp, oven.h]
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2026-04-09 Reorganize documentation structure
    [4.0 inches IO pin distribution.xlsx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]
